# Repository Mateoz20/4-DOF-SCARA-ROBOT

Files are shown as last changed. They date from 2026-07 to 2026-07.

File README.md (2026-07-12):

# 4-DOF SCARA Robot for Smart Visor Automation

Industrial Robotics course project — Politecnico di Milano (2025/26).

Design, modeling and simulation **from scratch** of a 4-axis collaborative SCARA robot that performs two pick-and-place / inspection trajectories, with full kinematics, dynamics, trajectory planning and motor sizing.

**Team:** Jessica Dichakdjian · Keylian Paris · Mateo Zeneli

<p align="center">
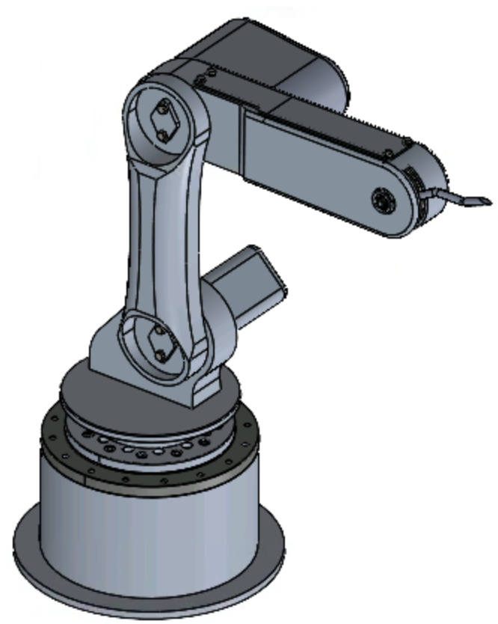
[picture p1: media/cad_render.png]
SCARA 4-DOF CAD render
  
</p>

---

## Overview

- **Robot:** 4-DOF SCARA arm, aluminum structure (6061-T6), revolute joints + belt drive (no gearbox)
- **Payload:** 0.5 kg (analyzed up to 1 kg)
- **Tools:** SolidWorks (CAD), MATLAB + Simulink/Simscape (kinematics, dynamics, simulation)
- **Motors:** Mitsubishi HG-MR13 / HG-MR23 servomotors, GT2 belt + pulley transmission

### The two tasks

| Trajectory | Method | Character |
|---|---|---|
| **A→B→B2→C** (ABC) | Lines & Parabolas (trapezoidal, minimum-time) | Fast pick-and-place; higher torque peaks |
| **A→D→D2→E** (ADE) | Cubic splines | Smooth inspection motion; lower dynamic stress |

Key results: Joint 2 (shoulder) dominates torque demand (peak ≈ 9.3 → 14.1 Nm with payload on ABC); MATLAB inverse dynamics validated against Simscape.

| Workspace (manipulability map) | Joint torques – ABC, 0.5 kg payload |
|---|---|
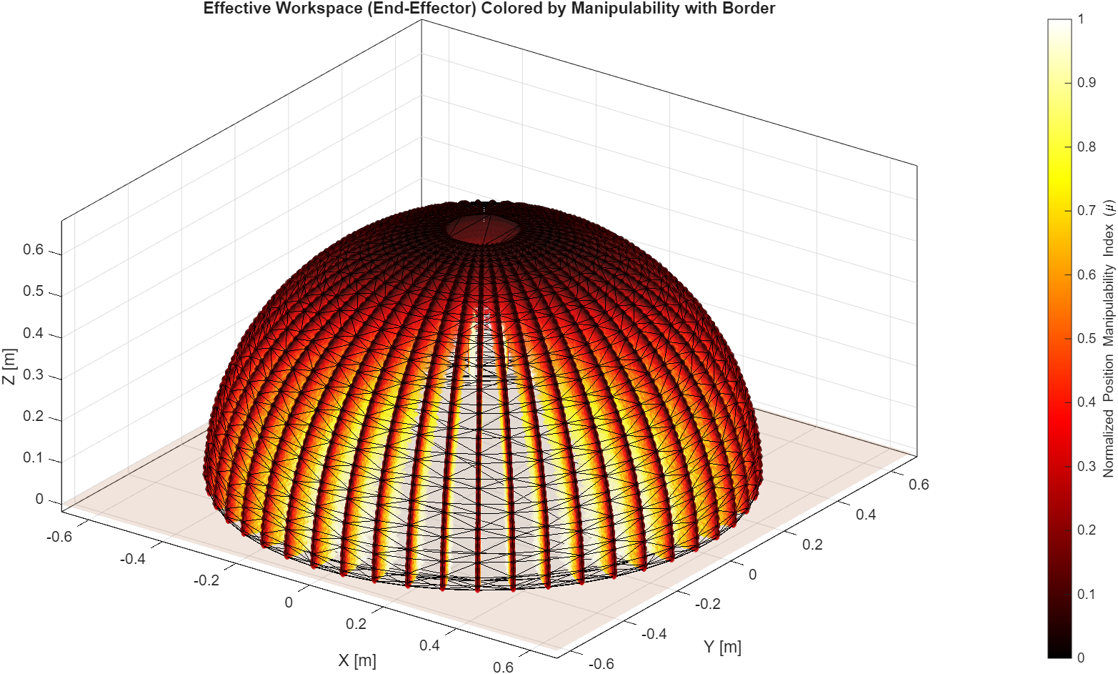
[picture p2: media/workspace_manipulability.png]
Workspace colored by manipulability
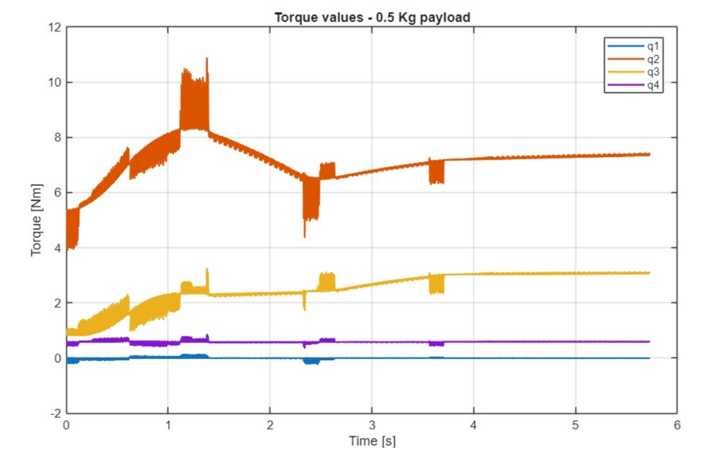
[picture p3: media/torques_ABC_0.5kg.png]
Joint torques ABC
|  |  |

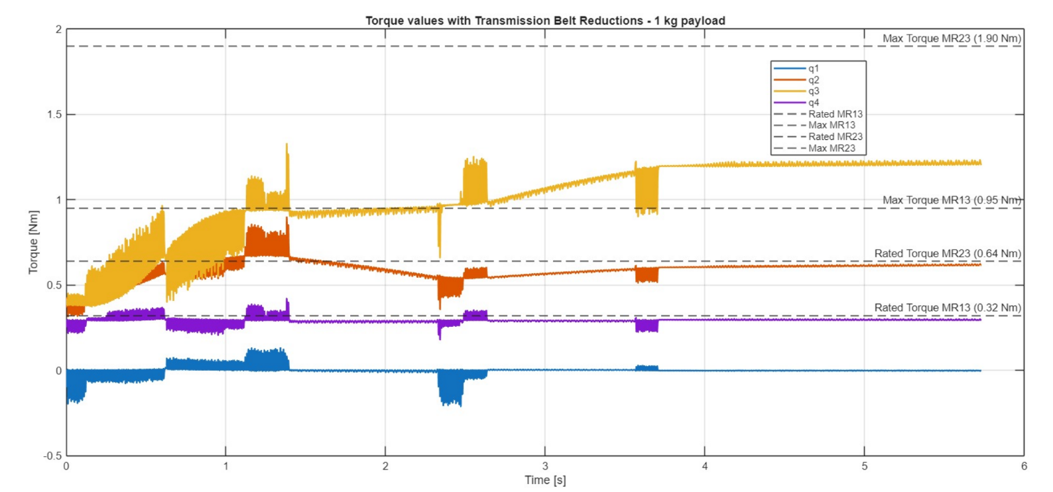
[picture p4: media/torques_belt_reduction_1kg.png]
Motor torques with belt reduction vs motor limits

*Motor-side torques with belt transmission (1 kg payload) vs HG-MR13 / HG-MR23 rated and max torque limits.*

---

## Repository structure

```
├── matlab/                  Kinematics, dynamics & trajectory planning
│   ├── ABC_Trajectory.m       Main script — ABC task (Lines & Parabolas)
│   ├── Main_ADE.m             Main script — ADE task (cubic splines)
│   ├── plot_simscape_values.m           Extract q, q̇, q̈, τ from Simscape run
│   ├── Comparison_Matlab_Simscape_ABCtraj.m   MATLAB vs Simscape validation
│   ├── Motor_sizing_Beta_Alpha.m        Motor sizing (α–β method, τ_opt)
│   ├── lib/                   Shared functions (IK/FK, Jacobian, M/C/G, profiles, plotting)
│   ├── demos/                 Kinematics test scripts (FK/IK check, S-shape motion)
│   ├── legacy/                Earlier trajectory iterations
│   └── data/                  Exported joint trajectories for Simscape (.mat)
├── simscape/                Multibody simulation
│   ├── SCARA_Simscape.slx     Simscape Multibody model
│   ├── step/                  STEP geometry imported by the model
│   ├── task_space/            Task-space planning: DH forward kinematics (fk_robot_13.m),
│   │                          numerical IK (fminsearch), Cartesian line+arc trajectory, Prova_2.slx
│   └── *.m                    Trajectory generation scripts used by the model
├── cad/                     Technical drawings (PDF) + Bill of Materials
│   ├── drawings/              Exploded views: base, arms, gripper, full assembly
│   └── step/                  Work-object geometry (helmet / visor STEP)
├── docs/                    Project presentation + motor datasheets
└── media/                   Simulation videos + README figures
```

## How to run

1. Open MATLAB in `matlab/` and add the helper folders to the path:
   ```matlab
   addpath('lib','demos','legacy','data')
   ```
2. Run a task:
   - `ABC_Trajectory` — trapezoidal (L&P) trajectory, dynamics, torque plots, animation; exports `SCARA_pos_simscape.mat`
   - `Main_ADE` — cubic-spline trajectory, dynamics, torque plots, 3D animation; exports `ADE_traj.mat`
3. Simulate in Simscape: open `simscape/SCARA_Simscape.slx` (loads the exported `.mat` joint signals via *From Workspace* blocks), then post-process with `plot_simscape_values.m` and compare using `Comparison_Matlab_Simscape_ABCtraj.m`.
4. Motor sizing: after a Simscape run, execute `Motor_sizing_Beta_Alpha.m` (α–β method with optimal transmission-ratio table).
5. Task-space planning: `simscape/task_space/` contains the full-DH forward kinematics, the numerical IK (`fminsearch`, sub-millimeter accuracy) and the Cartesian line + semicircle trajectory used in `Prova_2.slx`.

**Requirements:** MATLAB + Simulink + Simscape Multibody (R2023b or later recommended), Curve Fitting Toolbox (`fnder`).

## Documentation

- `docs/Project_Presentation.pptx` — full project presentation (CAD model, workspace map, dynamics, torque analysis, performance)
- `cad/BOM_SCARA_Assembly.pdf` — Bill of Materials
- `docs/HG-MR13.pdf`, `docs/HG-MR23.pdf` — servomotor datasheets

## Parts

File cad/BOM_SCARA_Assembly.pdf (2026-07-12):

LEVEL 1 | LEVEL 2 | LEVEL 3 | LEVEL 4 | N°
Scara_Assembly
| Base
| | Frame base | | 1
| | Servomotor_hg-mr13 | | 1
| | Hex nut M4 (ISO 4032) | | 2
| | Hex head screw M4×25 (ISO 4017) | | 14
| | Flat washer M4 (ISO 7089) | | 14
| | Slewing ring Ø100 mm | | 1
| | Flexible shaft coupling 8–8 mm | | 1
| Arm_00_Assembly
| | Hex head screw M4×45 (ISO 4017) | | 12
| | Flat washer M4 (ISO 7089) | | 16
| | Hex nut M4 (ISO 4032) | | 12
| | Waist | | 1
| | Deep groove ball bearing 618-8 | | 1
| | Flexible shaft coupling 8–8 mm | | 1
| | Servomotor_hg-mr13 | | 1
| | Frame motor | | 1
| | Hex socket head cap screw M4×20 (ISO 4762) | | 6
| Arm_01_Assembly
| | Frame Arm_01 | | 1
| | Deep groove ball bearing 618-8 | | 2
| | Joint_12 | | 2
| | Flat washer M5 (ISO 7089) | | 4
| | Hex head screw M5×12 (ISO 4017) | | 4
| Arm_02_Assembly
| | Main frame | | 1
| | Nylon insert lock nut M5 (ISO 10511) | | 1
| | Hex head screw M5×20 (ISO 4017) | | 1
| | Hex nut M4 (ISO 4032) | | 2

Plate_motor | | 1
Deep groove ball bearing 618-8 | | 1
Flexible shaft coupling 8–8 mm | | 1
Hex head screw M4×20 (ISO 4017) | | 4
Motor frame | | 1
Flat washer M5 (ISO 7089) | | 2
Hex head screw M5×8 (ISO 4017) | | 2
Upper frame | | 1
Flat washer M4 (ISO 7089) | | 6
Hex head screw M4×8 (ISO 4017) | | 4
Set screw M4×10 (ISO 4027) | | 2
Pulley tarnsmission | | 1
| GT2 timing pulley - 20 T - 8 mm bore - 10mm belt | 1
| GT2 timing pulley 80 T - 8 mm bore - 10 mm belt | 1
| GT2 timing belt - 10 mm width | 1
| Driven shaft | 1
| Deep groove ball bearing 618-8 | 2
| External retaining ring 8 mm (UNI 7435) | 2

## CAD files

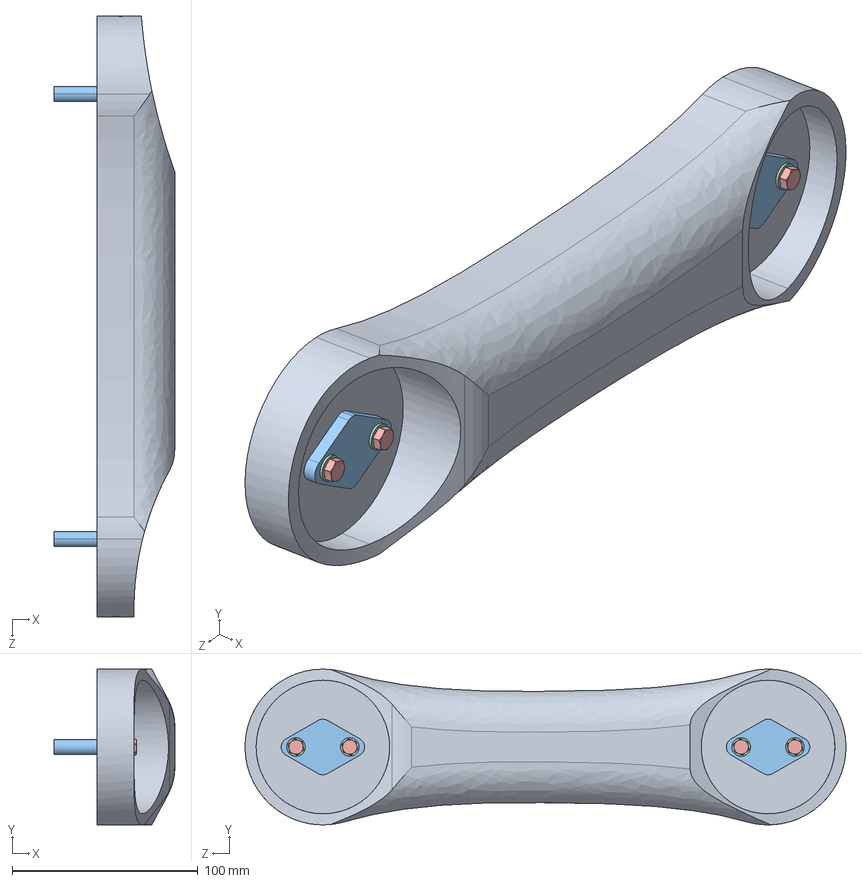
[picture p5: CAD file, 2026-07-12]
simscape/step/Arm_01_Assembly.STEP
65.0 x 84.0 x 324.0 mm
Arm_01
%3% BS 290 - SKF 618_8 x 2
Joint_12 x 2
din125-2-a5_3-300_hv.stp x 4
TR00003378-000.step x 4

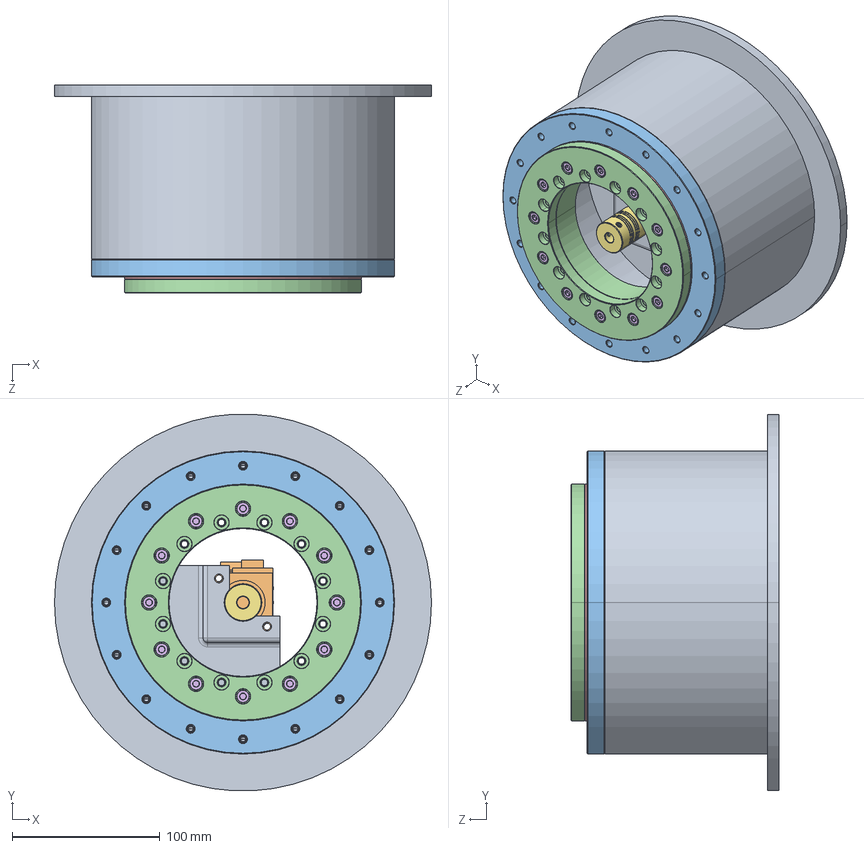
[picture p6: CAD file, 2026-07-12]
simscape/step/Base_Assembly.STEP
255.0 x 254.6 x 141.0 mm
Base
Servomotor_hg-mr13
PRT_01_100_M_ARGG_1.stp
PSR16-PSMR25-A_PSMR25-8-8-A.step
Metric Socket Set Screws 1_SFM4_8.step x 4

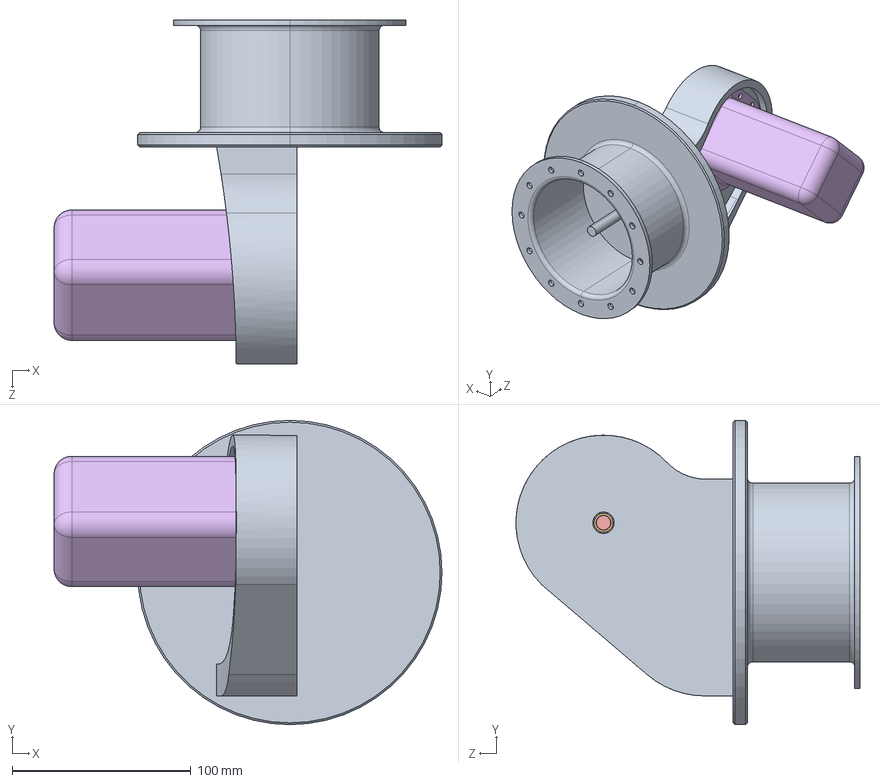
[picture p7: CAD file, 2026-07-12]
simscape/step/Arm_00_Assembly.STEP
217.1 x 170.3 x 192.6 mm
Waist
%3% BS 290 - SKF 618_8
PSR16-PSMR25-A_PSMR25-8-8-A.step
Metric Socket Set Screws 1_SFM4_8.step x 4
Servomotor_hg-mr13
Case_3

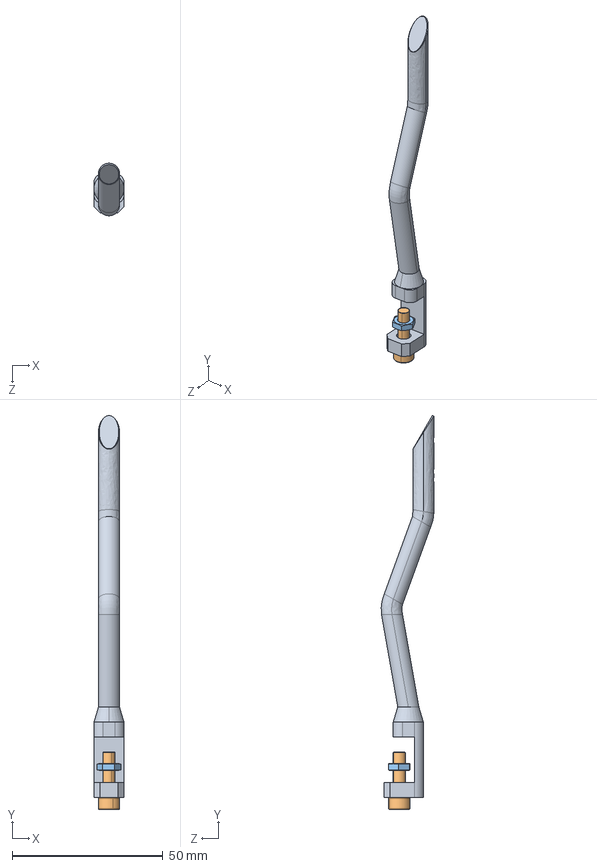
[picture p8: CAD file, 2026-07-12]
simscape/step/Gripper_Assembly.STEP
10.0 x 130.5 x 17.4 mm
Gripper
L Bolt M4 x 15 Stainless Steel
M4x2.2mm Hex Nut

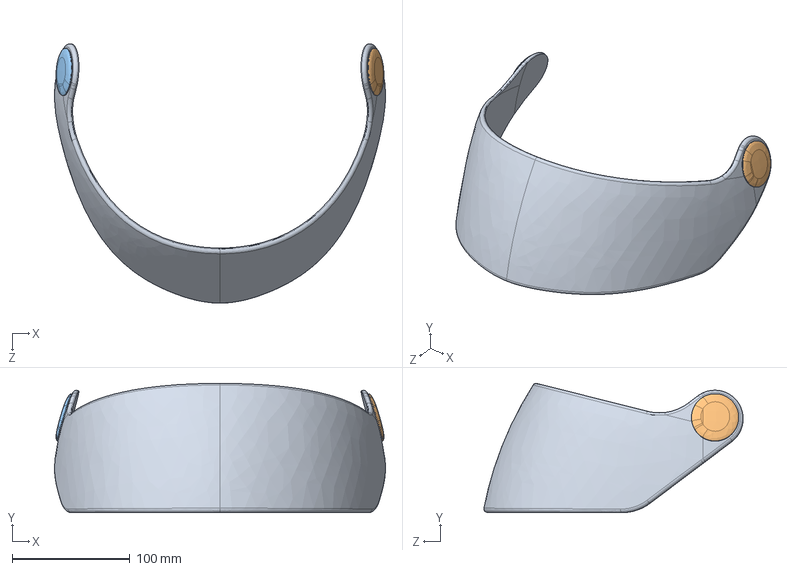
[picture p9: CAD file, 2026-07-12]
cad/step/VIS.STEP
281.4 x 109.9 x 220.5 mm

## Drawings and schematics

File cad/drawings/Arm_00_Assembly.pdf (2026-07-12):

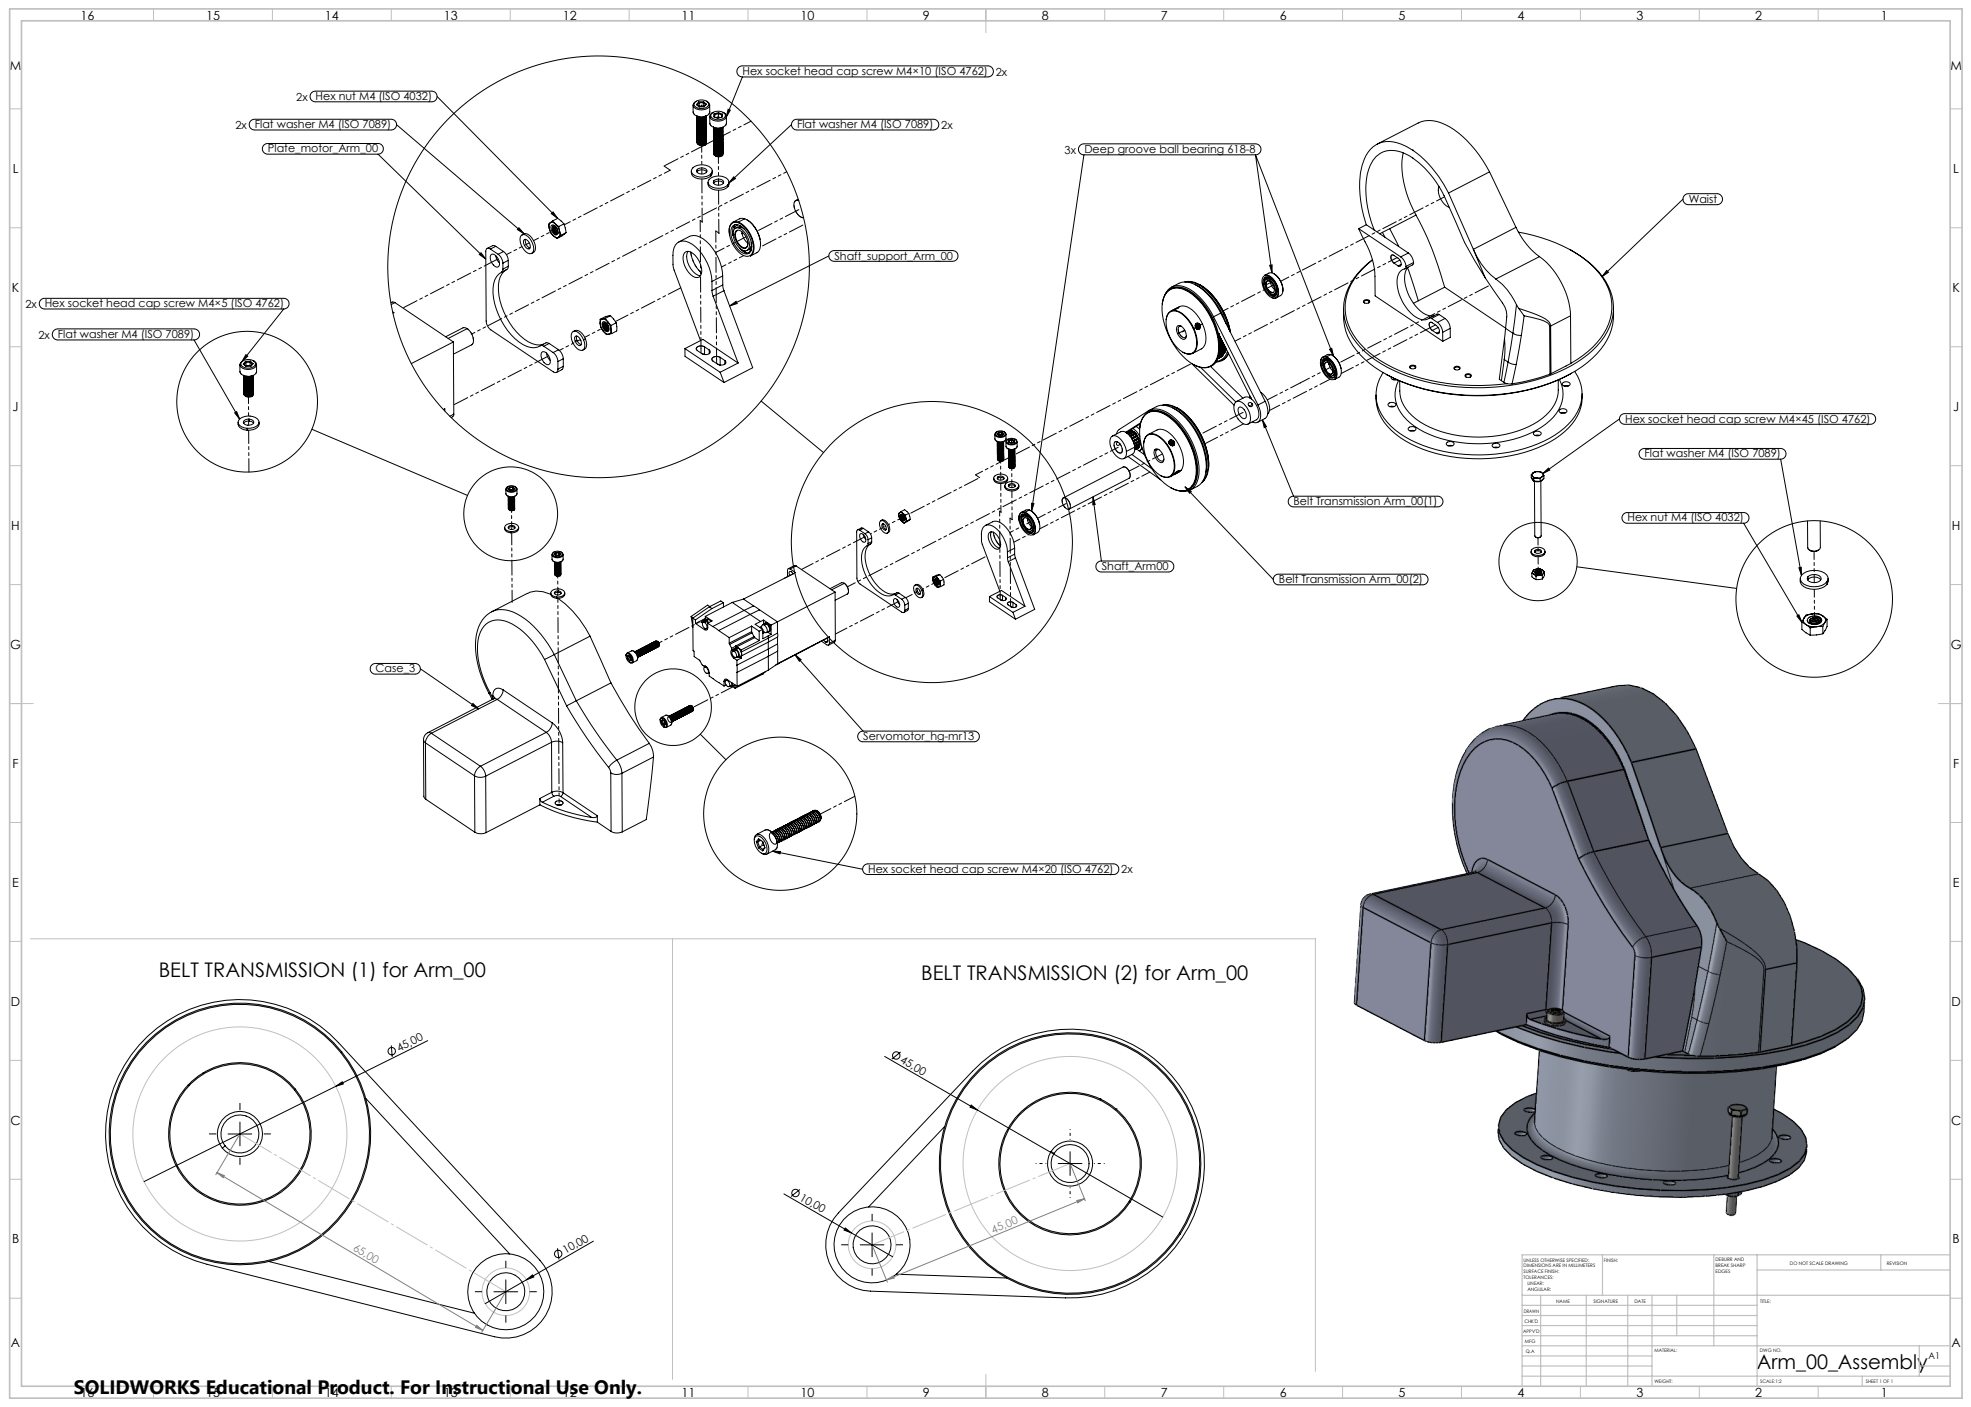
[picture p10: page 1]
Belt Transmission Arm_00(1); Belt Transmission Arm_00(2); FINISH:; DEBURR AND; BREAK SHARP; DO NOT SCALE DRAWING; REVISION; SCALE:1:2; SHEET 1 OF 1

Hex socket head cap screw M4×10 (ISO 4762) 2x

2x Hex nut M4 (ISO 4032)

2x Flat washer M4 (ISO 7089)
Plate_motor_Arm_00

Flat washer M4 (ISO 7089) 2x

3x Deep groove ball bearing 618-8

2x Hex socket head cap screw M4×5 (ISO 4762)

Hex socket head cap screw M4×45 (ISO 4762)

Flat washer M4 (ISO 7089)

Hex nut M4 (ISO 4032)

Hex socket head cap screw M4×20 (ISO 4762) 2x

BELT TRANSMISSION (1) for Arm_00

BELT TRANSMISSION (2) for Arm_00

UNLESS OTHERWISE SPECIFIED:
DIMENSIONS ARE IN MILLIMETERS
SURFACE FINISH:
TOLERANCES:
LINEAR:
ANGULAR:

NAME | SIGNATURE | DATE | | | | TITLE:

DRAWN
CHK'D
APPV'D
MFG
Q.A | | | | MATERIAL: | Arm_00_Assembly DWG NO. | A1

SOLIDWORKS Educational Product. For Instructional Use Only.

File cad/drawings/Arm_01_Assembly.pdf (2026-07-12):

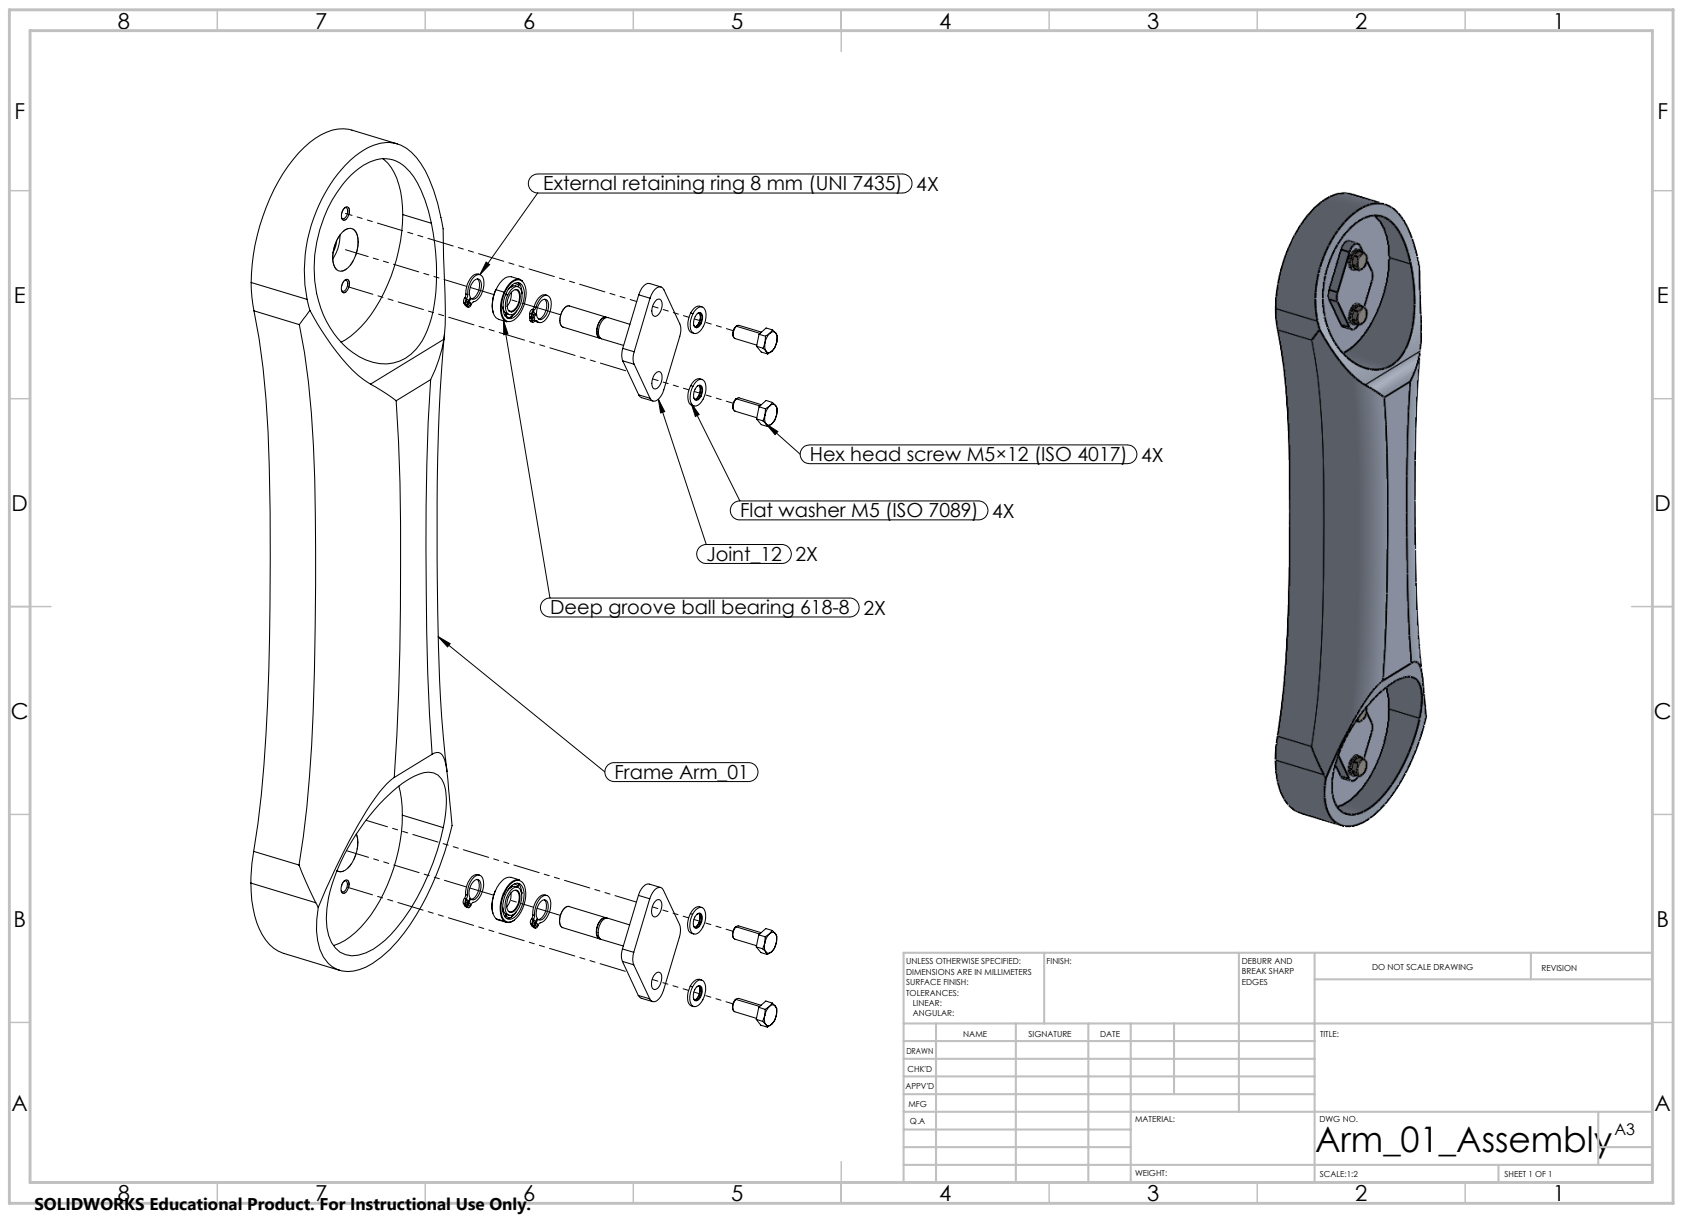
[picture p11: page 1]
Frame Arm_01; FINISH:; DEBURR AND; BREAK SHARP; DO NOT SCALE DRAWING; REVISION; SCALE:1:2; SHEET 1 OF 1

External retaining ring 8 mm (UNI 7435) 4X

Hex head screw M5×12 (ISO 4017) 4X

Flat washer M5 (ISO 7089) 4X
Joint_12 2X

Deep groove ball bearing 618-8 2X

UNLESS OTHERWISE SPECIFIED:
DIMENSIONS ARE IN MILLIMETERS
SURFACE FINISH:
TOLERANCES:
LINEAR:
ANGULAR:

NAME | SIGNATURE | DATE | | | | TITLE:

DRAWN
CHK'D
APPV'D
MFG
Q.A | | | | MATERIAL: | DWG NO. Arm_01_Assembly | A3

SOLIDWORKS Educational Product. For Instructional Use Only.

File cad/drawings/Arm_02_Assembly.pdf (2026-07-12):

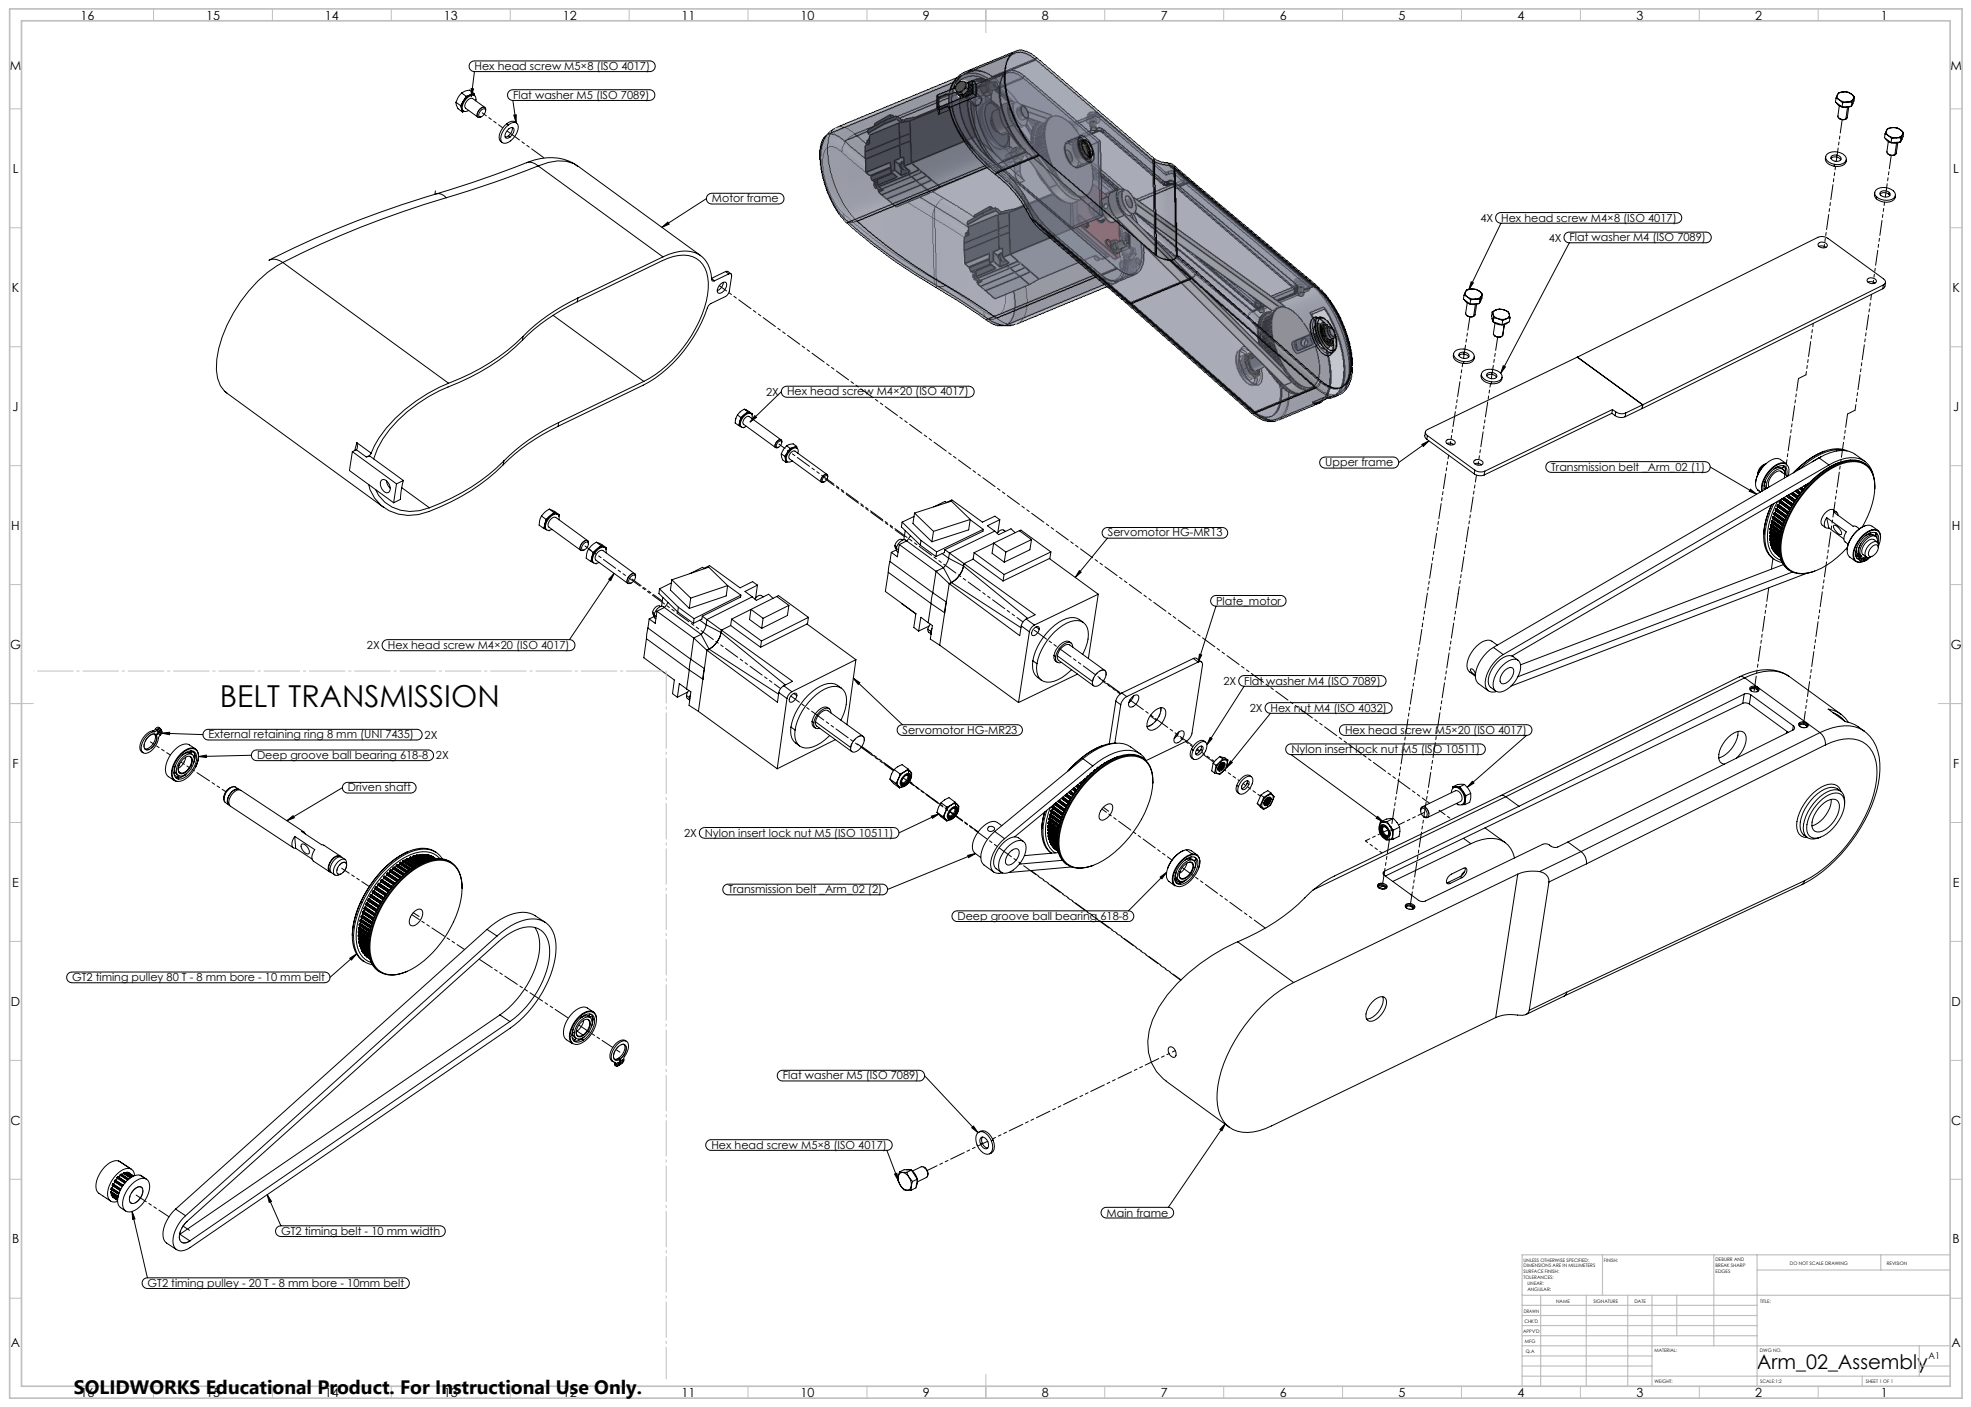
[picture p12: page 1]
Motor frame; Servomotor HG-MR13; Main frame; Transmission belt _Arm_02 (2); Servomotor HG-MR23; BELT TRANSMISSION; Driven shaft; FINISH:; DEBURR AND; BREAK SHARP; DO NOT SCALE DRAWING; REVISION; SCALE:1:2; SHEET 1 OF 1

Hex head screw M5×8 (ISO 4017)

Flat washer M5 (ISO 7089)

4X Hex head screw M4×8 (ISO 4017)

4X Flat washer M4 (ISO 7089)

2X Hex head screw M4×20 (ISO 4017)

Transmission belt _Arm_02 (1) Upper frame

2X Flat washer M4 (ISO 7089)
2X Hex nut M4 (ISO 4032)

Hex head screw M5×20 (ISO 4017)

External retaining ring 8 mm (UNI 7435) 2X

Nylon insert lock nut M5 (ISO 10511)

Deep groove ball bearing 618-8 2X

2X Nylon insert lock nut M5 (ISO 10511)

Deep groove ball bearing 618-8

GT2 timing pulley 80 T - 8 mm bore - 10 mm belt

GT2 timing belt - 10 mm width

UNLESS OTHERWISE SPECIFIED:
DIMENSIONS ARE IN MILLIMETERS
SURFACE FINISH:
TOLERANCES:
LINEAR:
ANGULAR:

GT2 timing pulley - 20 T - 8 mm bore - 10mm belt

NAME | SIGNATURE | DATE | | | | TITLE:

DRAWN
CHK'D
APPV'D
MFG
Q.A | | | | MATERIAL: | Arm_02_Assembly DWG NO. | A1

SOLIDWORKS Educational Product. For Instructional Use Only.

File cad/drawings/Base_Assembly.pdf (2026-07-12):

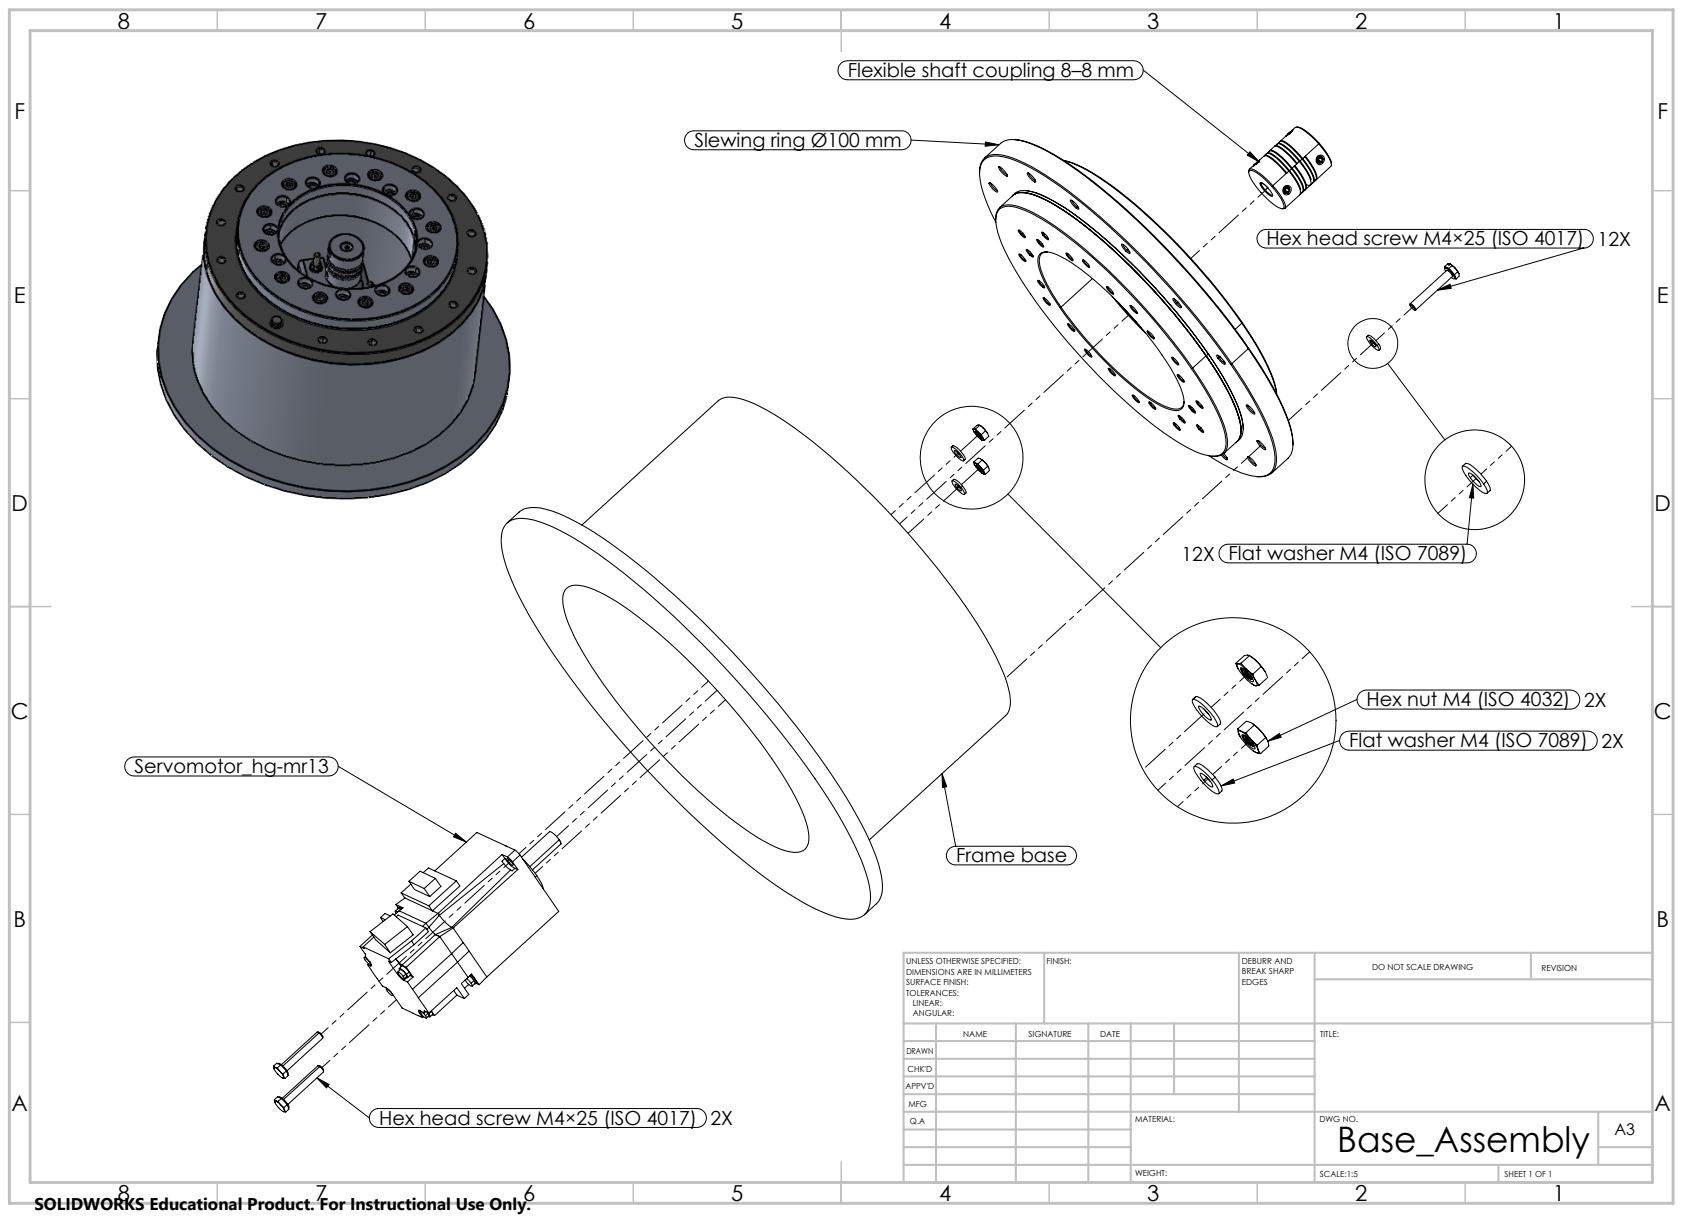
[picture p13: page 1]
Frame base; FINISH:; DEBURR AND; BREAK SHARP; DO NOT SCALE DRAWING; REVISION; SCALE:1:5; SHEET 1 OF 1

Flexible shaft coupling 8–8 mm

Slewing ring Ø100 mm

Hex head screw M4×25 (ISO 4017) 12X

12X Flat washer M4 (ISO 7089)

Hex nut M4 (ISO 4032) 2X
Flat washer M4 (ISO 7089) 2X

UNLESS OTHERWISE SPECIFIED:
DIMENSIONS ARE IN MILLIMETERS
SURFACE FINISH:
TOLERANCES:
LINEAR:
ANGULAR:

NAME | SIGNATURE | DATE | | | | TITLE:

DRAWN
CHK'D
APPV'D
MFG
Q.A | | | | MATERIAL: | DWG NO. Base_Assembly | A3

Hex head screw M4×25 (ISO 4017) 2X

SOLIDWORKS Educational Product. For Instructional Use Only.

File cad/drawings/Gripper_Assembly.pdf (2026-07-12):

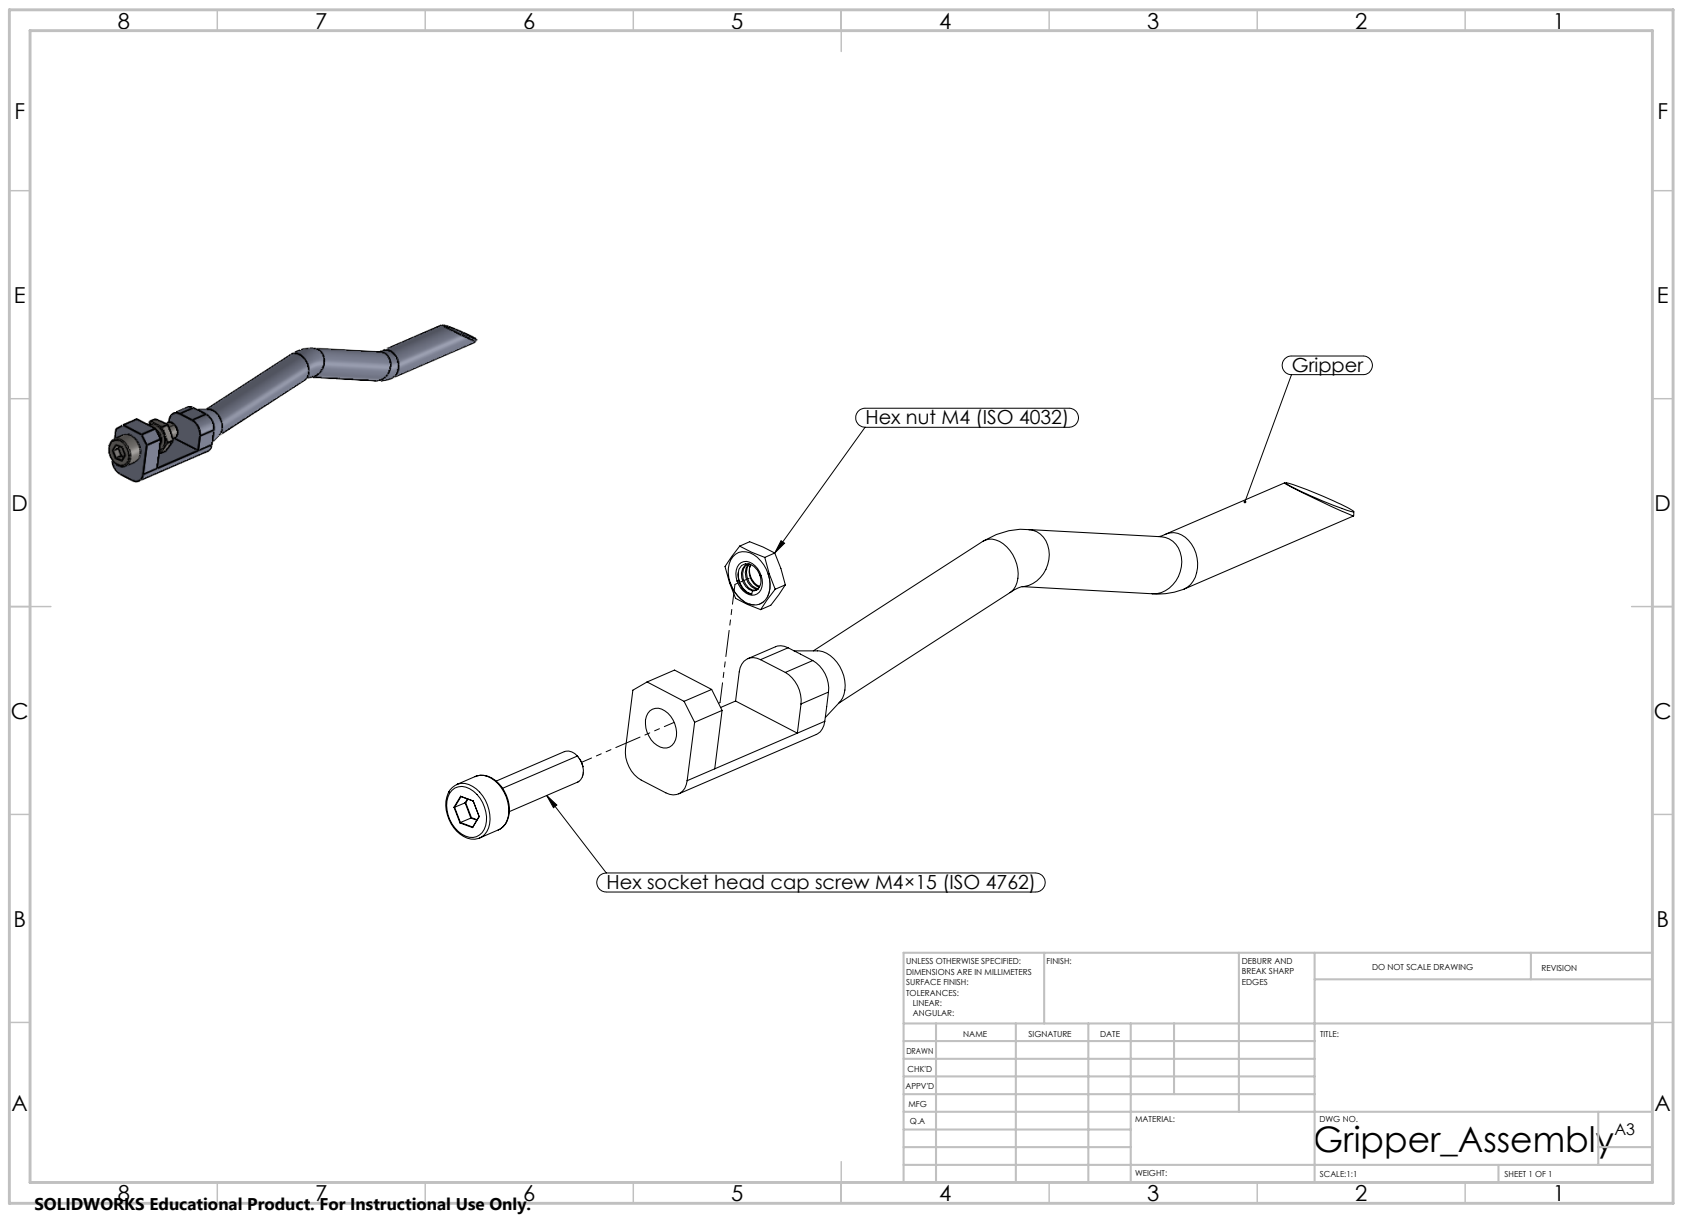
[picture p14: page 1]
FINISH:; DEBURR AND; BREAK SHARP; DO NOT SCALE DRAWING; REVISION; SCALE:1:1; SHEET 1 OF 1

Hex nut M4 (ISO 4032)

Hex socket head cap screw M4×15 (ISO 4762)

UNLESS OTHERWISE SPECIFIED:
DIMENSIONS ARE IN MILLIMETERS
SURFACE FINISH:
TOLERANCES:
LINEAR:
ANGULAR:

NAME | SIGNATURE | DATE | | | | TITLE:

DRAWN
CHK'D
APPV'D
MFG
Q.A | | | | MATERIAL: | DWG NO. Gripper_Assembly | A3

SOLIDWORKS Educational Product. For Instructional Use Only.

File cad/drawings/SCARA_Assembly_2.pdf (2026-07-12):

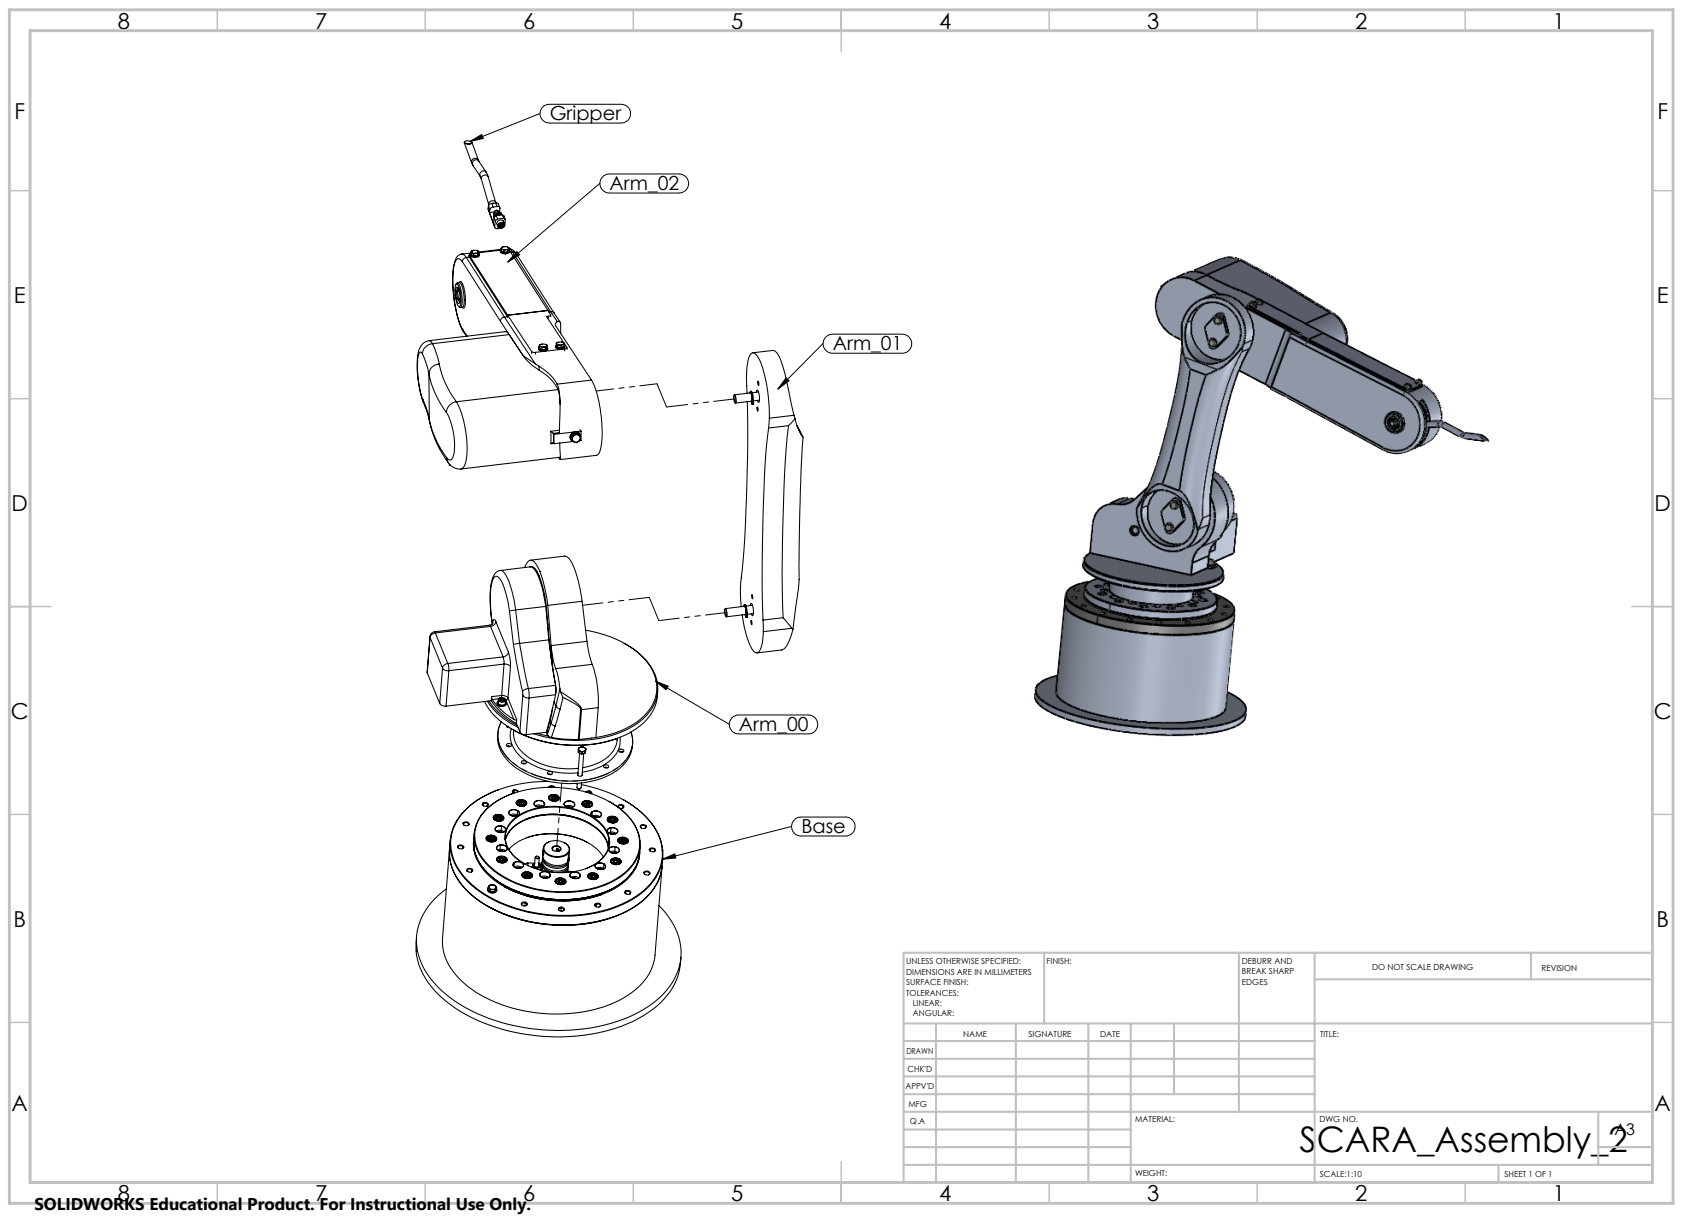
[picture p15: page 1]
FINISH:; DEBURR AND; BREAK SHARP; DO NOT SCALE DRAWING; REVISION; SCALE:1:10; SHEET 1 OF 1

UNLESS OTHERWISE SPECIFIED:
DIMENSIONS ARE IN MILLIMETERS
SURFACE FINISH:
TOLERANCES:
LINEAR:
ANGULAR:

NAME | SIGNATURE | DATE | | | | TITLE:

DRAWN
CHK'D
APPV'D
MFG
Q.A | | | | MATERIAL: SCARA_Assembly_2 | DWG NO. | A3

SOLIDWORKS Educational Product. For Instructional Use Only.

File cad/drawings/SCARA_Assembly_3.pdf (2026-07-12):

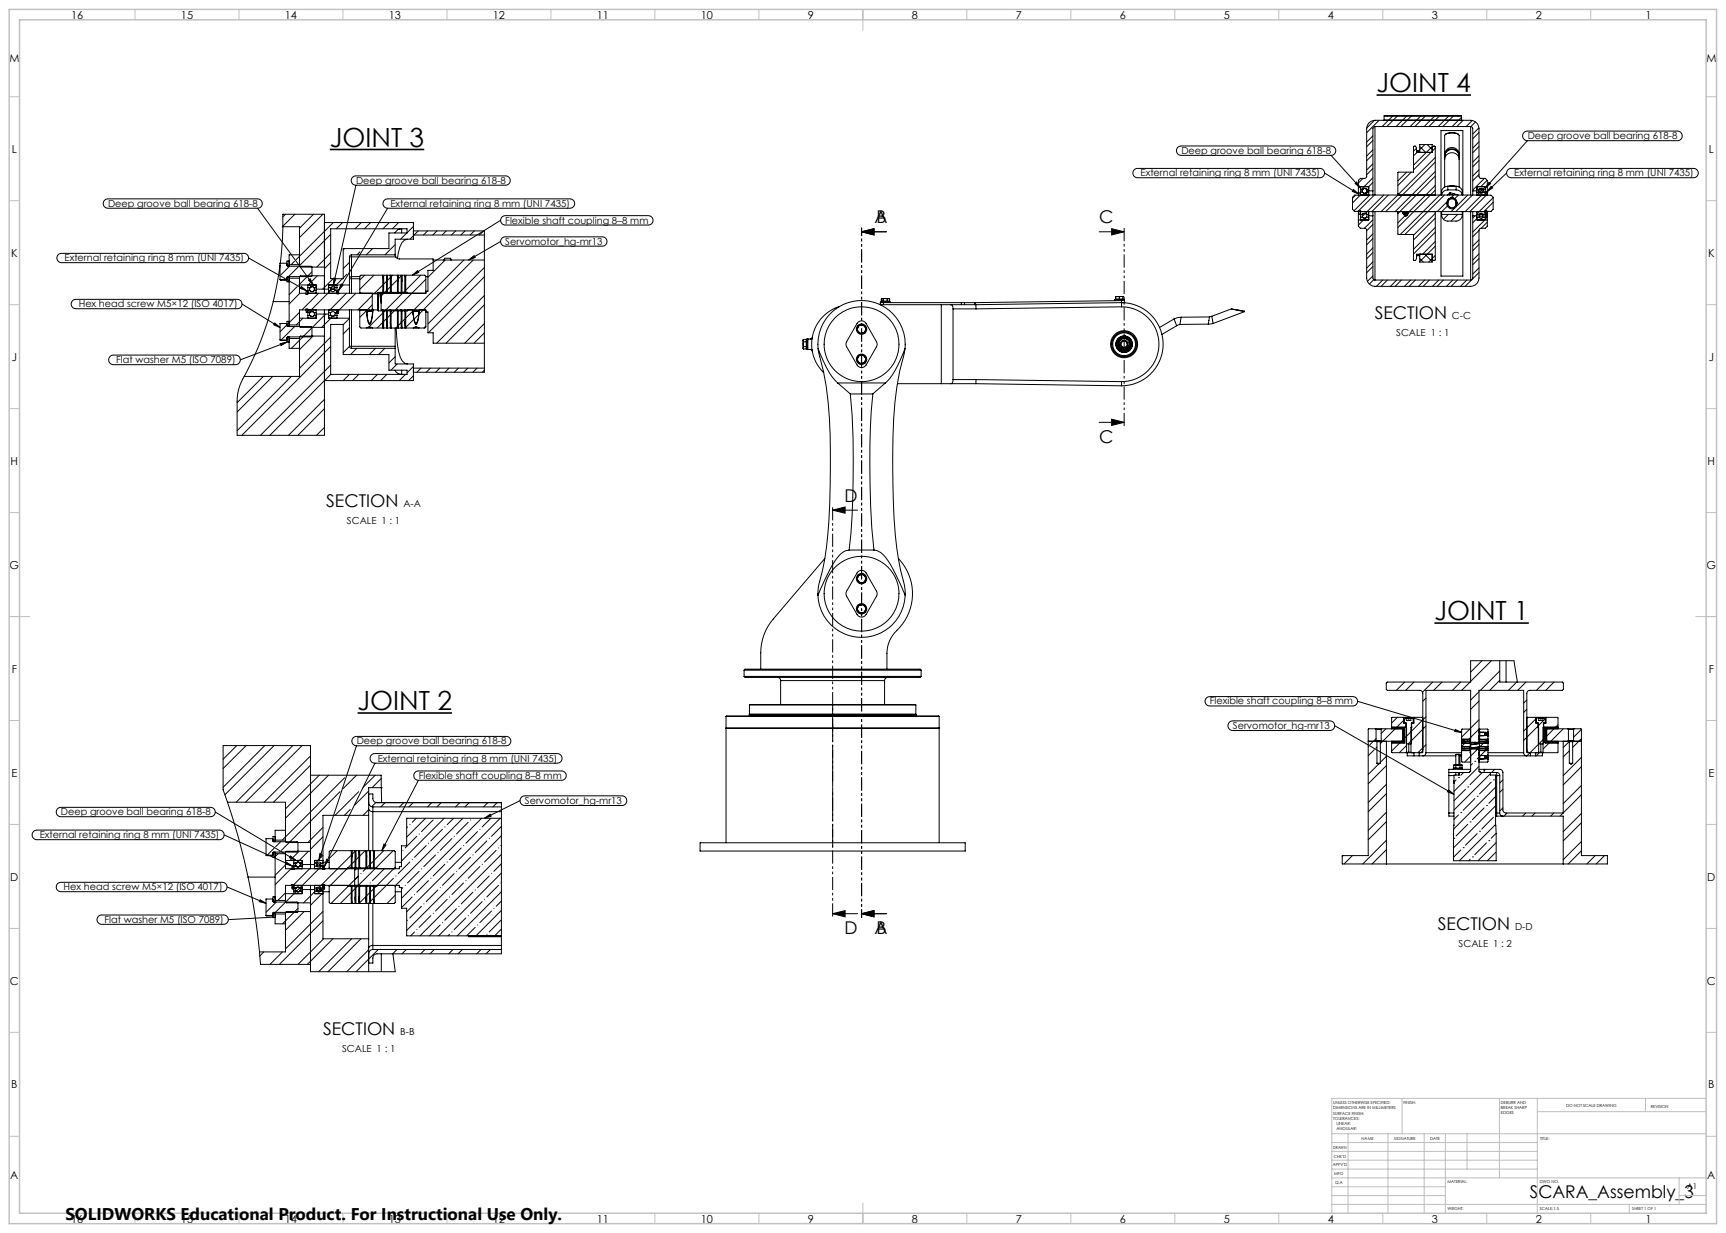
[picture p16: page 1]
SECTION A-A; SCALE 1 : 1; SECTION B-B; JOINT 2; SECTION C-C; JOINT 4; SECTION D-D; SCALE 1 : 2; JOINT 1; JOINT 3; FINISH:; DEBURR AND; BREAK SHARP; DO NOT SCALE DRAWING; REVISION; SCALE:1:5; SHEET 1 OF 1

Deep groove ball bearing 618-8

External retaining ring 8 mm (UNI 7435)

Flexible shaft coupling 8–8 mm
Servomotor_hg-mr13

Hex head screw M5×12 (ISO 4017)

Flat washer M5 (ISO 7089)

UNLESS OTHERWISE SPECIFIED:
DIMENSIONS ARE IN MILLIMETERS
SURFACE FINISH:
TOLERANCES:
LINEAR:
ANGULAR:

NAME | SIGNATURE | DATE | | | | TITLE:

DRAWN
CHK'D
APPV'D
MFG
Q.A | | | | MATERIAL: SCARA_Assembly_3 | DWG NO. | A1

SOLIDWORKS Educational Product. For Instructional Use Only.

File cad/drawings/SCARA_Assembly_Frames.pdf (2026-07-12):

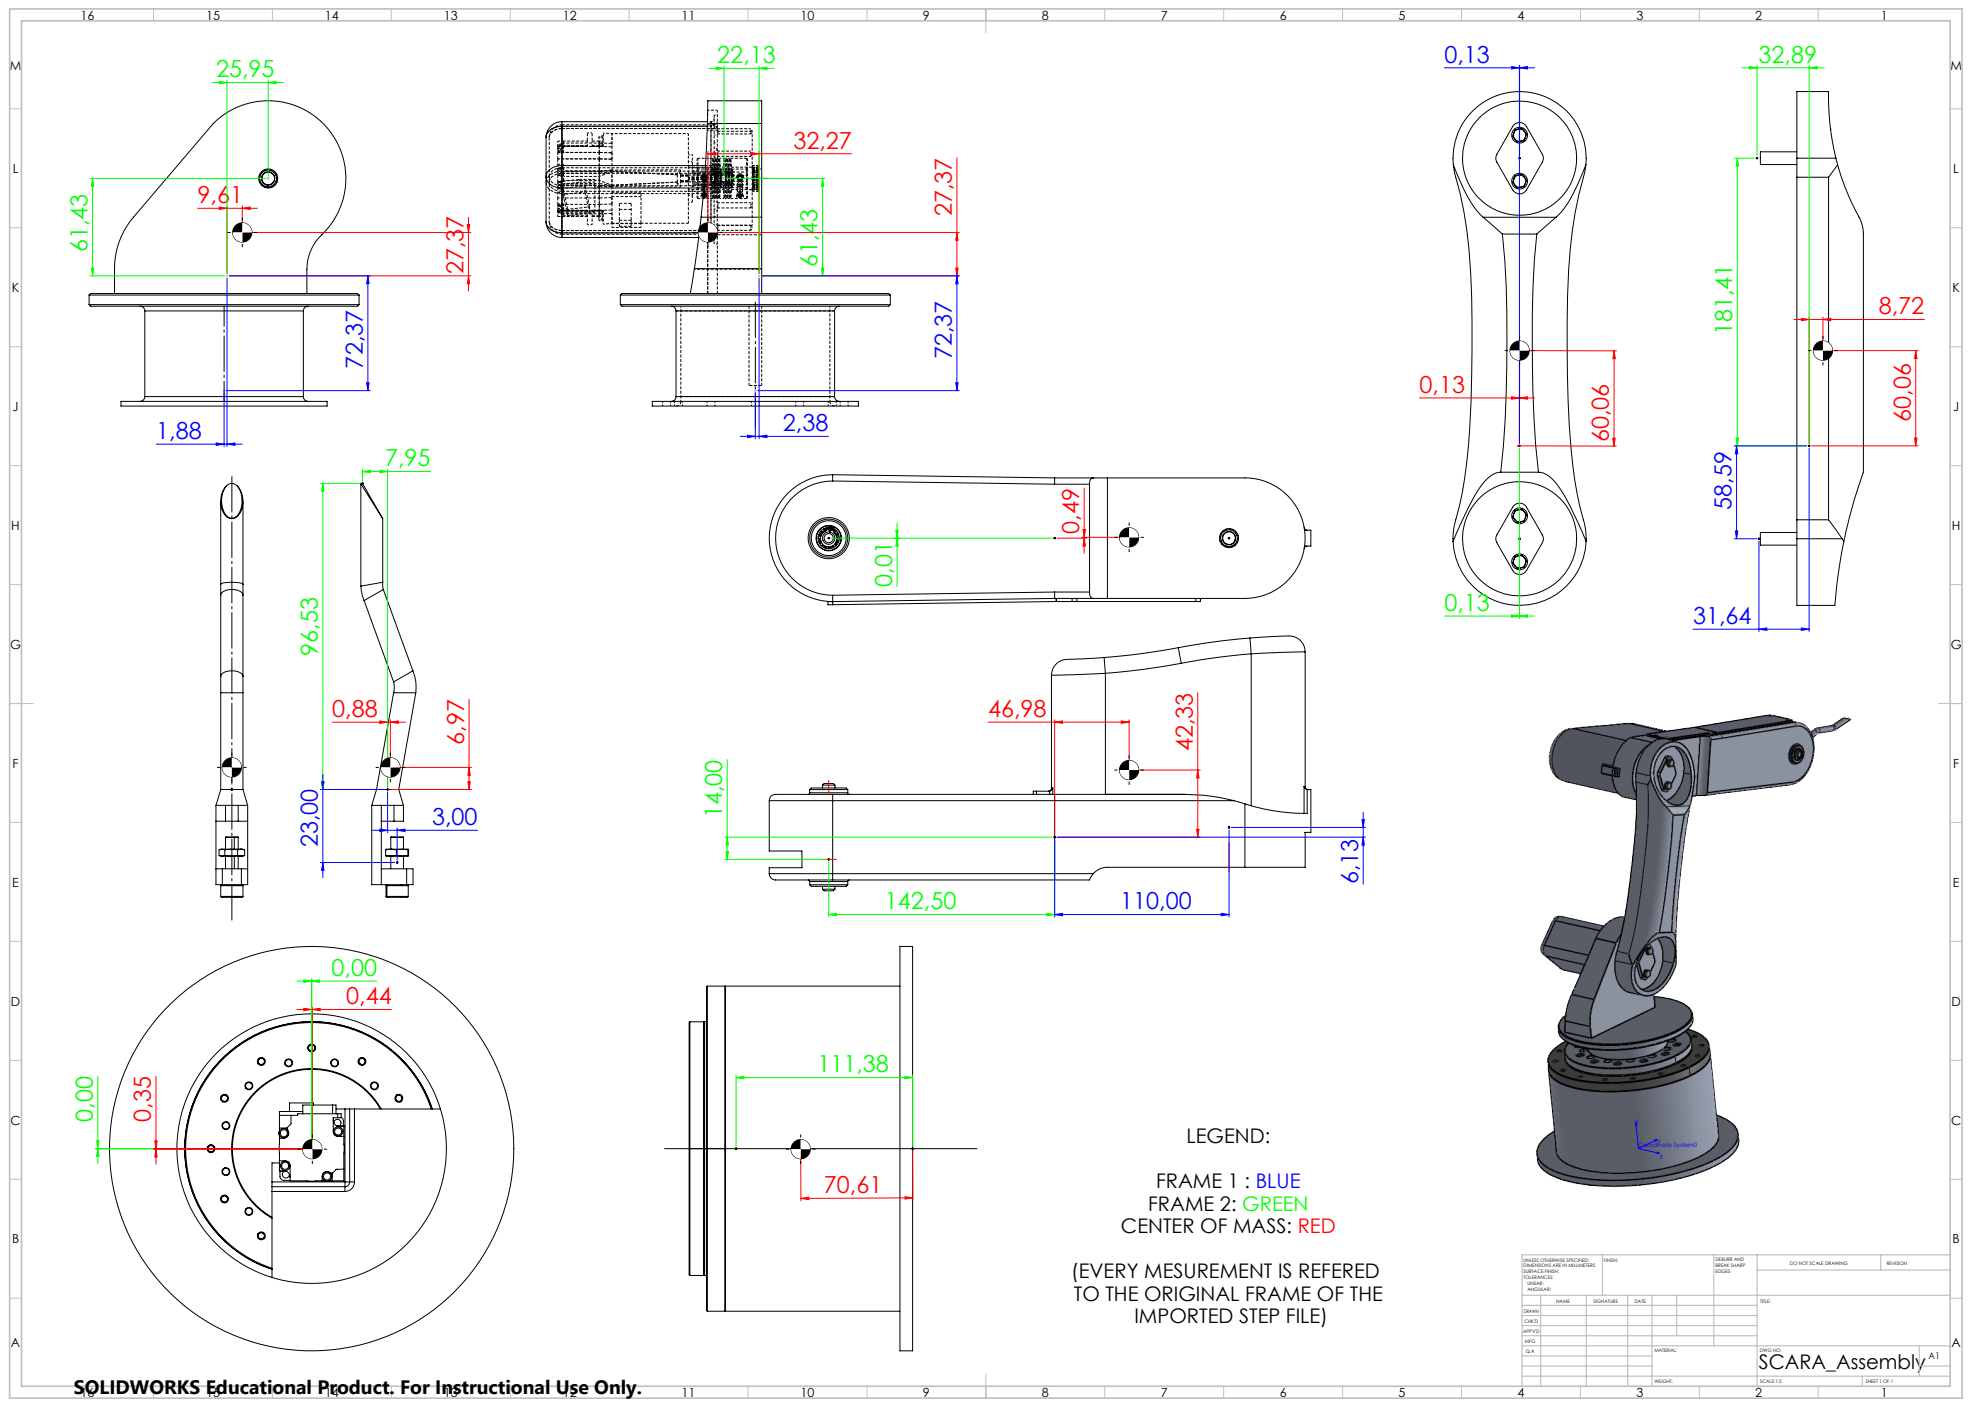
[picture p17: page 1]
Coordinate System0 Y; FINISH:; DEBURR AND; BREAK SHARP; DO NOT SCALE DRAWING; REVISION; SCALE:1:5; SHEET 1 OF 1

LEGEND:
FRAME 1 : BLUE
FRAME 2: GREEN
CENTER OF MASS: RED
(EVERY MESUREMENT IS REFERED
TO THE ORIGINAL FRAME OF THE
IMPORTED STEP FILE)

UNLESS OTHERWISE SPECIFIED:
DIMENSIONS ARE IN MILLIMETERS
SURFACE FINISH:
TOLERANCES:
LINEAR:
ANGULAR:

NAME | SIGNATURE | DATE | | | | TITLE:

DRAWN
CHK'D
APPV'D
MFG
Q.A | | | | MATERIAL: | SCARA_Assembly DWG NO. | A1

SOLIDWORKS Educational Product. For Instructional Use Only.
